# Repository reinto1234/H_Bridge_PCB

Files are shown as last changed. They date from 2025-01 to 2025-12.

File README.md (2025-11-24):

# H-Bridge PCB Project

## Project Description
This project involves the design and implementation of an **educational single-phase H-Bridge inverter** controlled by an **Espressif ESP32**.  
The system demonstrates **bipolar sinusoidal PWM (SPWM)** operation with **closed-loop VRMS amplitude control** and a **browser-based interface** for monitoring and control.  
The H-Bridge can drive loads with the following ratings:

- **Input Voltage:** 24 V  
- **Input Current:** up to 10 A  
- **Power:** ≈ 240 W  

### Features
- Fixed **switching frequency:** 35 kHz  
- Fixed **output frequency:** 50 Hz  
- **Bipolar SPWM modulation** (only)  
- **Closed-loop VRMS control** using PI regulation  
- **Web-based UI** (HTTP + WebSocket) for control and telemetry  
- **Input/Output power measurement**  
- **Overcurrent protection** using INA228 (auto driver shutdown + UI fault latch)  

The project consists of two main components:  
1. **H_Bridge_PCB_Design** — KiCad PCB layout and schematic.  
2. **H_Bridge_PCB_Code** — Firmware for the ESP32 controller.

---

## Directory Structure

<h2>Directory Structure</h2>
<pre><code>H_Bridge_PCB_Project/
├── H_Bridge_PCB_Design/        # KiCad design files
├── H_Bridge_PCB_Code/          # ESP32 firmware
│   ├── include/                # Header files
│   │   ├── Controller.h
│   │   ├── I2C.h
│   │   ├── Input_meas.h
│   │   ├── mutexdefinitions.h
│   │   ├── Output_meas.h
│   │   ├── PWM.h
│   │   ├── spi_sampler.h
│   │   ├── Tasks.h
│   │   └── webserver.h
│   │
│   ├── src/                    # Source files
│   │   ├── Controller.cpp
│   │   ├── I2C.cpp
│   │   ├── Input_meas.cpp
│   │   ├── Output_meas.cpp
│   │   ├── PWM.cpp
│   │   ├── spi_sampler.cpp
│   │   ├── Tasks.cpp
│   │   ├── webserver.cpp
│   │   └── main.cpp
│   │
│   ├── data/                   # Webserver files (LittleFS)
│   │   ├── index.html
│   │   ├── script.js
│   │   └── style.css
│
├── lib/                        # Optional local libraries
├── platformio.ini              # PlatformIO configuration
├── images/                     # Flowchart and figures
└── README.md                   # This file
</code></pre>

---

## Requirements

### Hardware:
- PCB based on KiCad design  
- 24 V DC power supply (≥ 10 A)  
- Resistive or inductive load (max ≈ 240 W)  
- Gate drivers with integrated dead-time  
- INA228 current/voltage monitor for input sensing  

### Software:
- [KiCad](https://www.kicad.org/) — PCB design  
- [PlatformIO](https://platformio.org/) — firmware build  
- [VS Code](https://code.visualstudio.com/) — recommended IDE  

---

## Webserver
The ESP32 provides a **built-in Wi-Fi access point** and hosts a **web-based interface** for control and measurement visualization.

### Connect to WLAN Access Point
- **SSID:** `H_Bridge_Control`  
- **Password:** `12345678`

### Open the web interface:
👉 [http://192.168.4.1/](http://192.168.4.1/)

**Functions:**
- Start/Stop the inverter  
- Set VRMS target  
- Display live telemetry (Vin, Iin, VRMS, IRMS, PF, P, Q, f)  
- View and acknowledge overcurrent faults  

---

## Code
The firmware is implemented in **C++** (Arduino / FreeRTOS).  
The web interface is built with **HTML**, **JavaScript**, and **CSS**.

---

### Flowchart
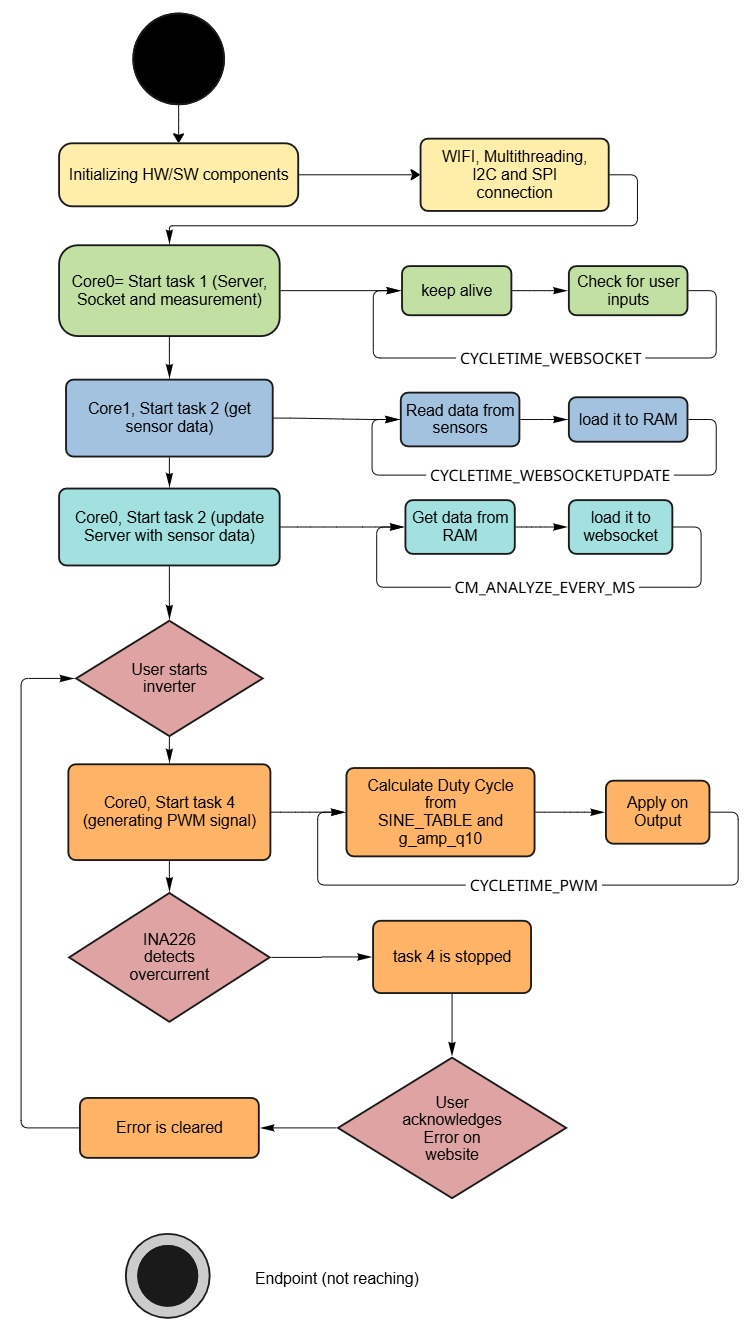
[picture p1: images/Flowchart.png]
Flowchart of the program


---

## Code Documentation
Brief overview of the most relevant components.

### Inverter Implementation (`PWM.cpp`)
Implements the real-time control of the full-bridge inverter:

- **startInverter()** — Initializes and enables PWM output.  
- **stopInverter()** — Stops PWM and resets inverter state.  
- **generateSPWM()** — Produces bipolar SPWM using a sine table.  
- **begin()** — Configures LEDC channels, frequency, and timers.  
- **getMeasurements()** — Retrieves latest measurement snapshot.  
- **computePI()** — Executes PI algorithm to maintain VRMS target.  
- **loop()** — Runs the inverter control logic at fixed timing intervals.  

### Controller Implementation (`Controller.cpp`)
Implements the PI controller used to regulate the inverter’s RMS output voltage:

- **PIController()** — Initializes PI gains, integrator state, limits, and VRMS target.  
- **ControlRMS()** — Computes RMS error and updates the global Q10 amplitude factor atomically.  
- **compute()** — Executes PI algorithm with anti-windup and output clamping to min/max limits.  
- **g_amp_q10** — Global Q10-formatted amplitude value used by the SPWM stage.  

### I²C Bus Setup (`I2C.cpp`)
Implements the I²C interface for the INA228 current/voltage sensor:

- **I2CINA** — Dedicated I²C bus instance (port 0) used by the input measurement subsystem.  

### Input Measurement (`Input_meas.cpp`)
Implements DC input voltage, current, and power measurement using INA228:

- **init()** — Initializes I²C bus, scans for devices, configures INA228, and sets averaging/timing.  
- **init1()** — Lightweight I²C initialization helper without full sensor setup.  
- **configure_overcurrent_alert_only()** — Configures INA228 alert registers for shunt overcurrent shutdown.  
- **getVoltage()** — Reads and returns the DC input voltage in volts.  
- **getCurrent()** — Reads and returns the shunt current in amperes.  
- **getPower()** — Reads and returns the input power in watts with simple error rejection.  
- **measurementall()** — Updates the shared input measurement buffer (voltage, current, power) in a mutex-protected way and returns it.  
- **scanI2C()** — Scans the I²C bus, prints found devices, and restarts the bus if no device is detected.  

### Main Application (`main.cpp`)
Implements system bring-up and FreeRTOS task orchestration:

- **setup()** — Initializes serial logging, mutexes, input measurement, Wi-Fi AP, webserver, SPI measurement engines, safety pins, and the overcurrent interrupt; then creates all application tasks.  
- **loop()** — Empty main loop; periodically yields since all logic is implemented in FreeRTOS tasks.  
- **Task handles** — Stores references to sampler, analyzer, WebSocket, controller, printer, and emergency stop tasks for debugging/management.  

### Mutex Definitions (`mutexdefinitions.cpp`)
Implements globally shared FreeRTOS mutexes for synchronization:

- **inverterMutex** — Protects access to the inverter state and control functions.  
- **measurementinMutex** — Protects shared input measurement buffer.  
- **measurementoutMutex** — Protects shared output measurement structures.  
- **measurementSpiMutex** — Protects SPI-related measurement buffers and state.  

### Output Measurement (`Output_meas.cpp`)
Implements decimation, CIC filtering, RMS, and frequency analysis for AMC1306 bitstreams:

- **buildByteCicLut()** — Precomputes CIC integrator/differentiator contributions for all 8-bit patterns.  
- **OutputMeasurements()** — Configures OSR, full-scale voltage, buffer sizes, and initial bit rate.  
- **init()** — Allocates decimation ring buffers, analysis windows, and period buffers (with PSRAM support) and creates a snapshot mutex.  
- **copyRecentWindowWithStats()** — Copies the newest segment from the decimation ring and computes mean, min, and max.  
- **findLastTwoRisingZcHyst()** — Detects the last two rising zero-crossings with hysteresis to define one AC period.  
- **computeRmsOnePeriodExact()** — Computes exact RMS over one period using piecewise linear interpolation.  
- **processRxBytesAndUpdateBitrate()** — Processes raw SPI bytes, runs CIC pipeline, generates decimated voltage samples, and updates effective bit rate.  
- **analyzeStep()** — Centers the signal, finds period boundaries, computes frequency, extracts a centered period, and calculates RMS.  
- **getSnapshot()** — Returns the latest snapshot (RMS, frequency, period length) in a thread-safe way.  
- **copyLastPeriod()** — Copies the last detected waveform period into a caller-provided buffer.  
- **copySinceSeq32()** — Provides incremental decimated samples since a given sequence index, for streaming or plotting.  

### Emergency Stop (`safety.cpp`)
Implements minimal emergency-stop signaling for overcurrent events:

- **g_emergency_stop** — Global volatile flag indicating an active emergency stop condition.  
- **onAlertISR()** — ISR that sets the emergency stop flag when the INA228 alert pin fires.  

### SPI Sampler (`spi_sampler.cpp`)
Implements DMA-driven SPI acquisition for dual AMC1306 isolated ADC channels:

- **g_ch1_om / g_ch2_om** — OutputMeasurements instances for both channels with hardware-specific scaling.  
- **g_sampler1 / g_sampler2** — Sampler context structures for SPI hosts, pins, DMA channels, and transactions.  
- **g_pack1 / g_pack2** — Pairs of sampler context and OutputMeasurements used by sampler tasks.  
- **spiSamplerInitMeasurements()** — Initializes both OutputMeasurements engines and validates buffer allocation.  
- **spiInitAndStart()** — Allocates DMA buffers, configures SPI bus and device, prepares transactions, and seeds the transaction queue.  

### Task Scheduler (`Tasks.cpp`)
Implements all FreeRTOS tasks for sampling, analysis, UI updates, control, and safety:

- **spiSamplerTask()** — Retrieves completed SPI DMA transactions, feeds data into OutputMeasurements, requeues transactions, and maintains sampling timing.  
- **analyzerTask()** — Periodically calls analyzeStep() on a given OutputMeasurements instance to update RMS and frequency.  
- **printerTask()** — Periodically prints analyzer timing, latest period samples, RMS, and frequency for both channels over serial.  
- **webSocketTask()** — Processes WebSocket events in a loop to keep client connections responsive.  
- **webSocketUpdate()** — Periodically collects input and output measurements and sends them as JSON via WebSocket to the UI.  
- **ControllerTask()** — Runs the VRMS control loop by feeding the measured RMS value into the PI controller of the inverter.  
- **EmergencyStopTask()** — Monitors the global emergency-stop flag, stops the inverter, signals the E-STOP output, and notifies the web UI when overcurrent is detected.  

### Webserver (`webserver.cpp`)
Implements Wi-Fi access point, HTTP endpoints, and WebSocket telemetry/UI control:

- **resetDefaults()** — Resets VRMS target and running state to their default values.  
- **initWiFi()** — Starts the Wi-Fi SoftAP for the H-Bridge control interface.  
- **initServer()** — Mounts LittleFS, serves static `/index.html`, `/style.css`, `/script.js`, and defines `/start`, `/stop`, and `/ack-trip` endpoints.  
- **updateMeasurements()** — Packs input/output data and frequency into JSON and broadcasts it over WebSocket.  
- **broadcastStatus()** — Sends current inverter running state to all connected clients via WebSocket.  
- **onWebSocketEvent()** — Handles client connect/disconnect events and sends initial status on connect.  
- **broadcastTrip()** — Notifies all clients of a trip condition and updates running state.  
- **_VRMS / _isRunning** — Static internal state for desired RMS value and inverter run/stop status.  

**HTTP Endpoints:**
- `/` – Main HTML page  
- `/start` – Start inverter  
- `/stop` – Stop inverter  
- `/update` – Update VRMS target  
- `/bipolar.png` – Waveform reference  

---

## Overcurrent Protection
Overcurrent protection is implemented through the **INA228** fault pin:  
1. When a current threshold is exceeded, **drivers are disabled immediately**.  
2. A **fault message** is sent to the web interface.  
3. After user acknowledgment, the inverter can be restarted safely.  

---

## Safety  
- Use **current-limited** power supplies during development.  
- Verify **MOSFET temperature and load** ratings.  
- For **educational/laboratory use only**.

---

## License
Released for **educational and research purposes**.  
Use responsibly.

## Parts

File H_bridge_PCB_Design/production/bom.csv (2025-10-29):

Designator | Footprint | Quantity | Value | LCSC Part #
C1, C6 | 0805 | 2 | 2.2 uF | C513763
C10, C13, C18, C19, C22, C24, C30, C33, C35, C9 | 0805 | 10 | 100 nF | C49678
C11, C17, C21, C25, C26, C27 | 0805 | 6 | 1µF | C28323
C12, C31, C32, C34, C36 | 0805 | 5 | 1 µF | C28323
C14, C15 | 0805 | 2 | 220nF | C354366
C16 | B32776E4406J000 | 1 | B32776E4406J000
C2, C4 | 0805 | 2 | 220 nF | C354366
C20 | 0805 | 1 | 4.7 µF | C49678
C23, C7, C8 | EEE1AA101SP | 3 | 100uF | C128464
C28, C29 | 0805 | 2 | 1 uF | C28323
C3, C5 | 0805 | 2 | 22 nF | C2181592
D1, D2, D3, D5 | FSV2060L | 4 | FSV2060L | C110669
D10, D11, D6, D7, D8, D9 | DIOM5336X265N | 6 | S210 | C184977
D12 | HPZRC26X | 1 | HPZR-C26X
D4 | SOT-143 | 1 | SP0503BAHT | C7074
FL1 | PHBC24N2R0A0219V | 1 | PHBC24N-2R0A0219V
IC1, IC3 | SOIC127P1150X280-8N | 2 | AMC1306M25DWVR | C471874
IC2 | L7812ABD2TTR | 1 | L7812ABD2T-TR | C186698
J1, J12, J14, J15, J2, J3, J4, J5, J7, J9 | TSW-102-XX-YY-S | 10 | TSW-102-15-T-S
J13 | 17345101 | 1 | 1734510-1 | C720612
LED1, LED4 | 0805 | 2 | TLMG1100-GS15-1 | C434436
LED2 | 0805 | 1 | TLMG1100-GS15-2 | C434436
LED3 | 0805 | 1 | TLMG1100-GS15-3 | C434436
PS1 | NXJ1S0303MCR13 | 1 | NXJ1S0303MC-R13 | C6943307
Q1, Q2, Q3, Q4 | TO254P483X1016X1994-3P | 4 | IRLB4030PBF | C2663
Q10, Q5, Q6, Q9 | IPD90N10S4L06ATMA1 | 4 | IPD90N10S4L06ATMA1
Q7, Q8 | SOT-23_Handsoldering | 2 | BC817 | C475629
R1, R10 | 0805 | 2 | 2.2 | C25301
R11, R27 | 0805 | 2 | 100 | C115423
R12 | 0805 | 1 | 1 | C4129769
R13, R18 | 0805 | 2 | 12k | C139925
R14 | 0805 | 1 | 5k | C2828700
R15, R42 | 2512 | 2 | GMR100HTBFER015 | C2985715
R16 | 0805 | 1 | 120k | C473315
R17, R28 | 0805 | 2 | 1k | C95781
R19, R20, R23, R24 | 0805 | 4 | 0 | C2074219
R2, R3, R8, R9 | 0805 | 4 | 10 | C3016584
R29 | 0805 | 1 | 330 | C4129769
R30, R31, R4, R40, R41, R5, R6, R7 | 0805 | 8 | 10k | C84376
S1 | B3U-1000P | 1 | B3U-1000P | C231329
TP1, TP2, TP3, TP4 | 5754 | 4 | 575-4
U1 | ESP32-WROOM-32 | 1 | ESP32-WROOM-32 | C701343
U2, U3 | SOIC-16W_7.5x10.3mm_P1.27mm | 2 | IR2110S | C2968
U4 | VSSOP-10_3x3mm_P0.5mm | 1 | INA228 | C2862904
U5 | SOT-223-3_TabPin2 | 1 | LT1963AxST-3.3 | C459918
U6 | TO-252-2 | 1 | LD1086DT50TR | C164853
U7 | SOIC-16_3.9x9.9mm_P1.27mm | 1 | CH340C | C84681

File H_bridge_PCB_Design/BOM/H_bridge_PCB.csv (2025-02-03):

Reference | Value | Footprint | Qty | DNP | LCSC Part#
C13,C16,C22 | MKS4C042204C00KSSD | SamacSys_Parts:MKS4C042204C00KSSD | 3
IC5 | ACS37800KMACTR-030B3-I2C | ACS37002LMCA050U5 | 1 | Nicht bestücken
J1,J2,J3,J4,J5,J6,J7,J8,J9,J10,J11 | TMS-102-21-G-S | SamacSys_Parts:TMS-102-YY-XX-S | 11 | Nicht bestücken
L1 | IH15BQ5R0K | SamacSys_Parts:IH15BQ5R0K | 1 | Nicht bestücken
Q1,Q2,Q3,Q4 | IRLB4030PBF | TO254P483X1016X1994-3P | 4 | Nicht bestücken
Q5,Q6,Q9,Q10 | IPD90N10S4L06ATMA1 | IPD90N10S4L06ATMA1 | 4 | Nicht bestücken
R46,R47 | 0 | Resistor_SMD:R_0805_2012Metric_Pad1.20x1.40mm_HandSolder | 2 | Nicht bestücken
TP1,TP2,TP3,TP4 | 575-4 | SamacSys_Parts:5754 | 4 | Nicht bestücken
U8 | 3544-2 | SamacSys_Parts:3544-2 | 1 | Nicht bestücken
P1 | USB_C_Plug_USB2.0 | Connector_USB:USB_C_Receptacle_HCTL_HC-TYPE-C-16P-01A | 1 |  | C2894897
U2,U3 | IR2110S | Package_SO:SOIC-16W_7.5x10.3mm_P1.27mm | 2 |  | C2968
D4 | SP0503BAHT | Package_TO_SOT_SMD:SOT-143 | 1 |  | C7074
U5 | LD1086DT33TR | Package_TO_SOT_SMD:TO-252-2 | 1 |  | C12051
U7 | CH340G | Package_SO:SOIC-16_3.9x9.9mm_P1.27mm | 1 |  | C14267
R1,R10 | 2.2 | Resistor_SMD:R_0805_2012Metric_Pad1.20x1.40mm_HandSolder | 2 |  | C25301
C11,C17,C21,C25,C26,C27 | 1µF | Resistor_SMD:R_0805_2012Metric_Pad1.20x1.40mm_HandSolder | 6 |  | C28323
C12 | 1 µF | Resistor_SMD:R_0805_2012Metric_Pad1.20x1.40mm_HandSolder | 1 |  | C28323
C10,C18,C19 | 100 nF | -- verschiedene Werte -- | 3 |  | C49678
R4,R5,R6,R7,R30,R31,R38,R39,R40,R41 | 10k | Resistor_SMD:R_0805_2012Metric_Pad1.20x1.40mm_HandSolder | 10 |  | C84376
R28 | 1k | Resistor_SMD:R_0805_2012Metric_Pad1.20x1.40mm_HandSolder | 1 |  | C95781
D1,D2,D3,D5 | FSV2060L | FSV2060L | 4 |  | C110669
R27 | 100 | Resistor_SMD:R_0805_2012Metric_Pad1.20x1.40mm_HandSolder | 1 |  | C115423
C7,C8,C23 | 100uF | SamacSys_Parts:EEE1AA101SP | 3 |  | C128464
R13 | 12k | Resistor_SMD:R_0805_2012Metric_Pad1.20x1.40mm_HandSolder | 1 |  | C139925
U6 | LD1086DT50TR | Package_TO_SOT_SMD:TO-252-2 | 1 |  | C164853
C9 | 1 nF | Resistor_SMD:R_0805_2012Metric_Pad1.20x1.40mm_HandSolder | 1 |  | C165822
D6,D7,D8,D9,D10,D11 | S210 | SamacSys_Parts:DIOM5336X265N | 6 |  | C184977
IC2 | L7812ABD2T-TR | L7812ABD2TTR | 1 |  | C186698
C2,C4 | 220 nF | Resistor_SMD:R_0805_2012Metric_Pad1.20x1.40mm_HandSolder | 2 |  | C354366
C14,C15 | 220nF | Resistor_SMD:R_0805_2012Metric_Pad1.20x1.40mm_HandSolder | 2 |  | C354366
LED1 | TLMG1100-GS15-1 | Resistor_SMD:R_0805_2012Metric_Pad1.20x1.40mm_HandSolder | 1 |  | C434436
LED2 | TLMG1100-GS15-2 | Resistor_SMD:R_0805_2012Metric_Pad1.20x1.40mm_HandSolder | 1 |  | C434436
LED3 | TLMG1100-GS15-3 | Resistor_SMD:R_0805_2012Metric_Pad1.20x1.40mm_HandSolder | 1 |  | C434436
Q7,Q8 | BC817 | Package_TO_SOT_SMD:SOT-23_Handsoldering | 2 |  | C475629
C1,C6 | 2.2 uF | Resistor_SMD:R_0805_2012Metric_Pad1.20x1.40mm_HandSolder | 2 |  | C513763
U1 | ESP32-WROOM-32 | RF_Module:ESP32-WROOM-32 | 1 |  | C701343
R23,R24,R48,R49 | 0 | Resistor_SMD:R_0805_2012Metric_Pad1.20x1.40mm_HandSolder | 4 |  | C2074219
C3,C5 | 22 nF | Resistor_SMD:R_0805_2012Metric_Pad1.20x1.40mm_HandSolder | 2 |  | C2181592
R15,R16,R43,R44 | 1M | Resistor_SMD:R_0805_2012Metric_Pad1.20x1.40mm_HandSolder | 4 |  | C2771009
R14 | 5k | Resistor_SMD:R_0805_2012Metric_Pad1.20x1.40mm_HandSolder | 1 |  | C2828700
U4 | INA228 | Package_SO:VSSOP-10_3x3mm_P0.5mm | 1 |  | C2862904
R42 | GMR100HTBFER015 | Resistor_SMD:R_2512_6332Metric_Pad1.40x3.35mm_HandSolder | 1 |  | C2985715
R2,R3,R8,R9 | 10 | Resistor_SMD:R_0805_2012Metric_Pad1.20x1.40mm_HandSolder | 4 |  | C3016584
R29 | 330 | Resistor_SMD:R_0805_2012Metric_Pad1.20x1.40mm_HandSolder | 1 |  | C4129769
R45 | 40k | Resistor_SMD:R_0805_2012Metric_Pad1.20x1.40mm_HandSolder | 1 |  | C5266069

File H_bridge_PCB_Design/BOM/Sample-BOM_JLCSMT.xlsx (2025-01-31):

Comment | Designator | Footprint | JLCPCB Part #（optional）
100uF | C1 | CAP-SMD_L3.5-W2.8 | C16133
15K | R5,R6 | R0603 | C22809
DC-005-20A_C136744 | DC1 | DC-IN-TH_DC-005-20A | C136744
Header-Female-2.54_1x8 | P2,P3 | HDR-TH_8P-P2.54-V | C27438
K2-1102DP-C4SW-04 | SW1 | KEY-TH_4P-L6.0-W6.0-P4.50-LS6.5 | C110153
ATMEGA328P-PU | U1 | DIP-28_L34.6-W7.3-P2.54-LS10.2-BL | C33901
670688000 | USB1 | USB-B-TH_67068-8000 | C114097

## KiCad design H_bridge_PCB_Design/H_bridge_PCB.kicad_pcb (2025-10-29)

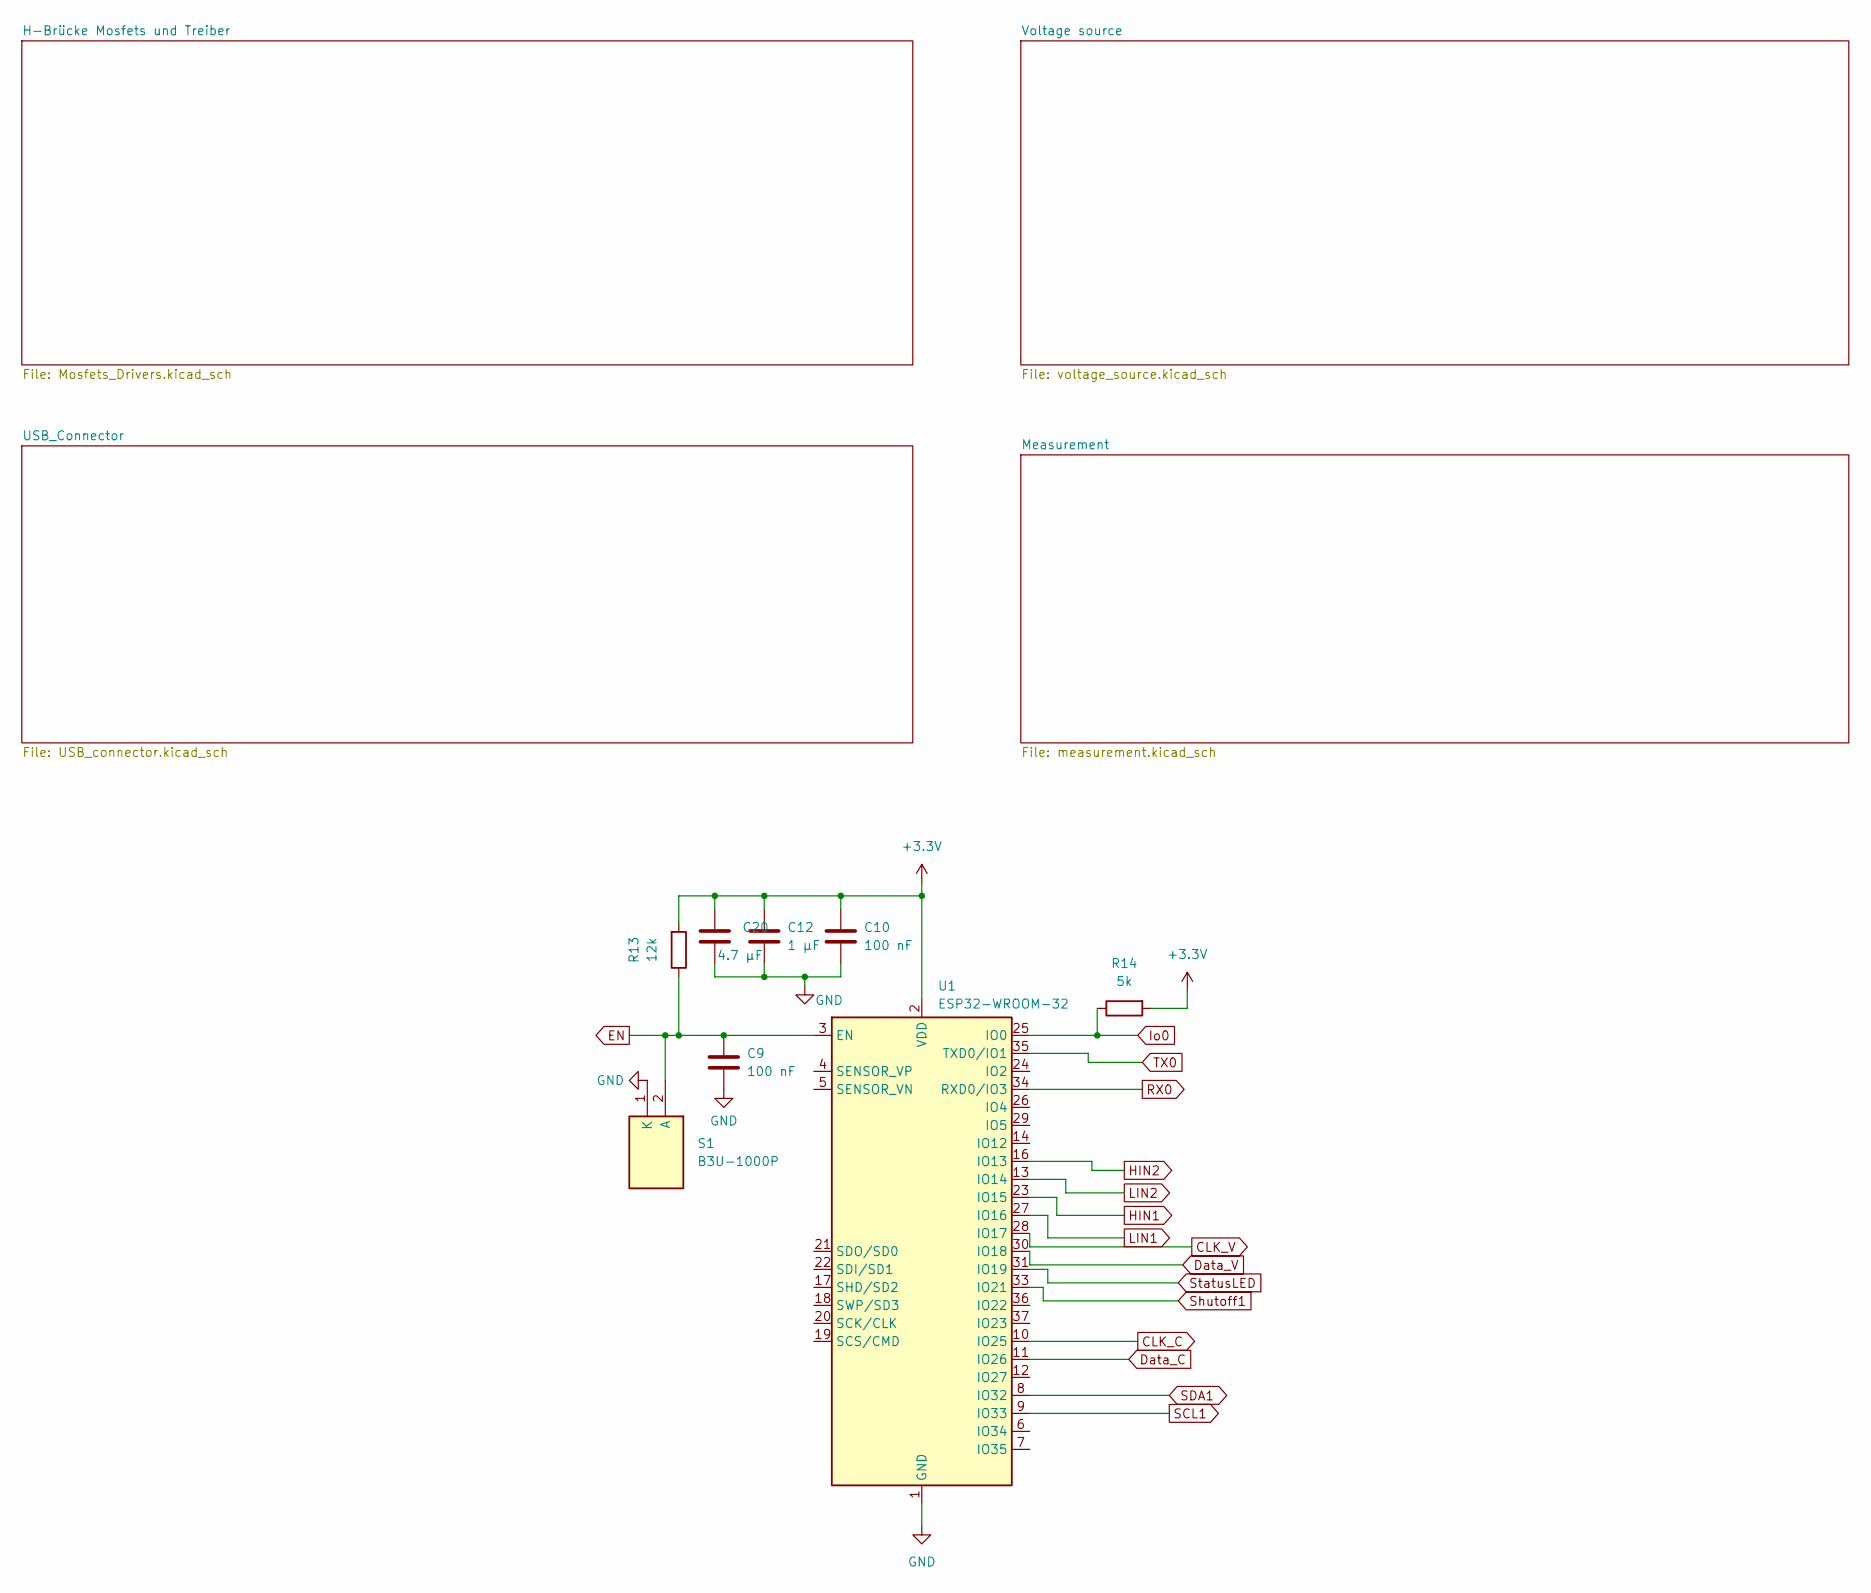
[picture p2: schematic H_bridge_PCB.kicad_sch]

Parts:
C9, C10: 100 nF; R_0805_2012Metric_Pad1.20x1.40mm_HandSolder; LCSC Part # C49678
C12: 1 µF; R_0805_2012Metric_Pad1.20x1.40mm_HandSolder; LCSC Part # C28323
C20: 4.7 µF; R_0805_2012Metric_Pad1.20x1.40mm_HandSolder; LCSC Part # C49678
R13: 12k; R_0805_2012Metric_Pad1.20x1.40mm_HandSolder; LCSC Part # C139925
R14: 5k; R_0805_2012Metric_Pad1.20x1.40mm_HandSolder; LCSC Part # C2828700
S1: B3U-1000P; Manufacturer_Part_Number B3U-1000P; Mouser Part Number 653-B3U-1000P
U1: ESP32-WROOM-32; LCSC Part # C701343

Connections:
+3.3V: C10.1, C12.1, C20.1, R13.2, R14.2, U1.2 (VDD); also elsewhere on the board
CLK_C: U1.10 (IO25); also elsewhere on the board
CLK_V: U1.28 (IO17); also elsewhere on the board
Data_C: U1.11 (IO26); also elsewhere on the board
Data_V: U1.30 (IO18); also elsewhere on the board
EN: C9.1, R13.1, S1.2 (A), U1.3 (EN); also elsewhere on the board
GND: C9.2, C10.2, C12.2, C20.2, S1.1 (K), U1.1 (GND), U1.15 (GND), U1.38 (GND), U1.39 (GND); also elsewhere on the board
HIN1: U1.23 (IO15); also elsewhere on the board
HIN2: U1.16 (IO13); also elsewhere on the board
Io0: R14.1, U1.25 (IO0); also elsewhere on the board
LIN1: U1.27 (IO16); also elsewhere on the board
LIN2: U1.13 (IO14); also elsewhere on the board
RX0: U1.34 (RXD0/IO3); also elsewhere on the board
SCL1: U1.9 (IO33); also elsewhere on the board
SDA1: U1.8 (IO32); also elsewhere on the board
Shutoff1: U1.33 (IO21); also elsewhere on the board
StatusLED: U1.31 (IO19)
TX0: U1.35 (TXD0/IO1); also elsewhere on the board

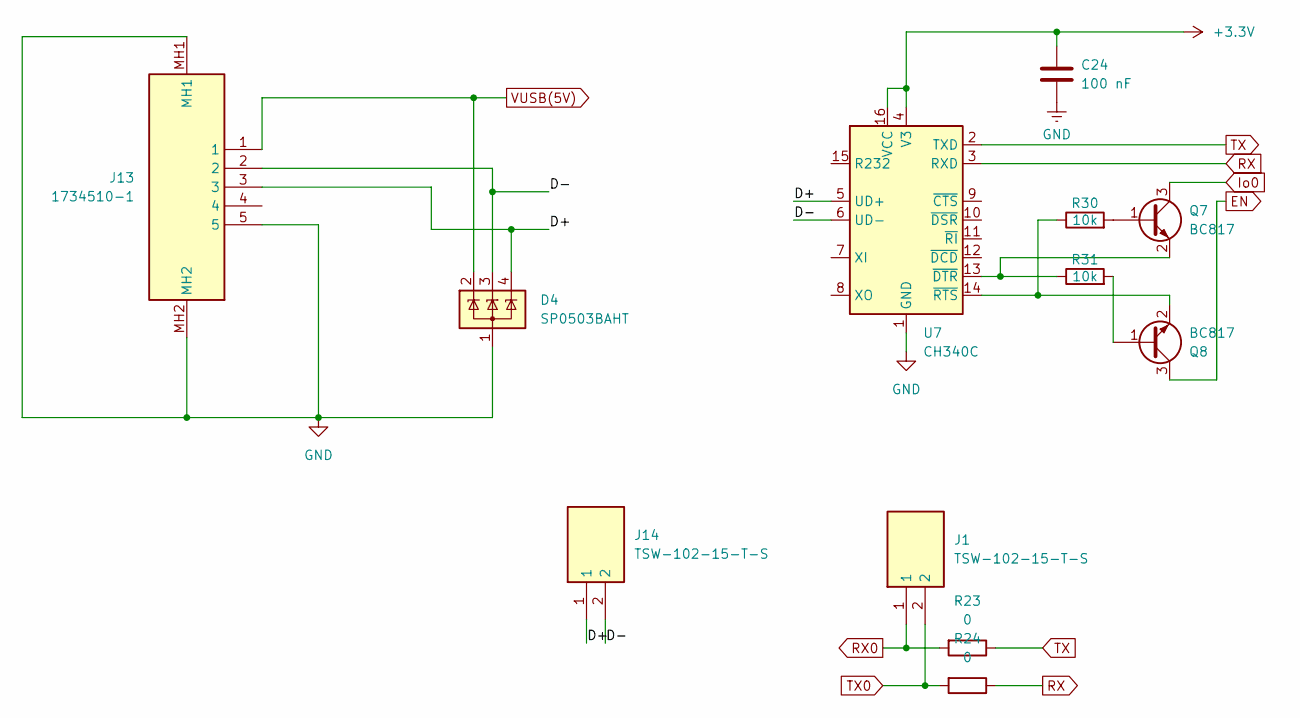
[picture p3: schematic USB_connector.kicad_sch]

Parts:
C24: 100 nF; R_0805_2012Metric_Pad1.20x1.40mm_HandSolder; LCSC Part # C49678
D4: SP0503BAHT; SOT-143; LCSC Part # C7074
J1, J14: TSW-102-15-T-S; TSW-102-XX-YY-S; Mouser Part Number 200-TSW10215TS
J13: 1734510-1; 17345101; Mouser Part Number 571-1734510-1
Q7, Q8: BC817; SOT-23_Handsoldering; LCSC Part # C475629
R23, R24: 0; R_0805_2012Metric_Pad1.20x1.40mm_HandSolder; LCSC Part # C2074219
R30, R31: 10k; R_0805_2012Metric_Pad1.20x1.40mm_HandSolder; LCSC Part # C84376
U7: CH340C; SOIC-16_3.9x9.9mm_P1.27mm; LCSC Part # C84681

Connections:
+3.3V: C24.1, U7.4 (V3), U7.16 (VCC); also elsewhere on the board
/USB_Connector/D+: D4.4 (K), J13.3, J14.1, U7.5 (UD+)
/USB_Connector/D-: D4.3 (K), J13.2, J14.2, U7.6 (UD-)
EN: Q8.3 (C); also elsewhere on the board
GND: C24.2, D4.1 (A), J13.5, J13.MH1, J13.MH2, U7.1 (GND); also elsewhere on the board
Io0: Q7.3 (C); also elsewhere on the board
unnamed: Q7.1 (B), R30.2
unnamed: Q7.2 (E), R31.1, U7.13 (~DTR)
unnamed: Q8.1 (B), R31.2
unnamed: Q8.2 (E), R30.1, U7.14 (~RTS)
RX: R24.1, U7.3 (RXD)
RX0: J1.1, R23.2; also elsewhere on the board
TX: R23.1, U7.2 (TXD)
TX0: J1.2, R24.2; also elsewhere on the board
VUSB(5V): D4.2 (K), J13.1; also elsewhere on the board

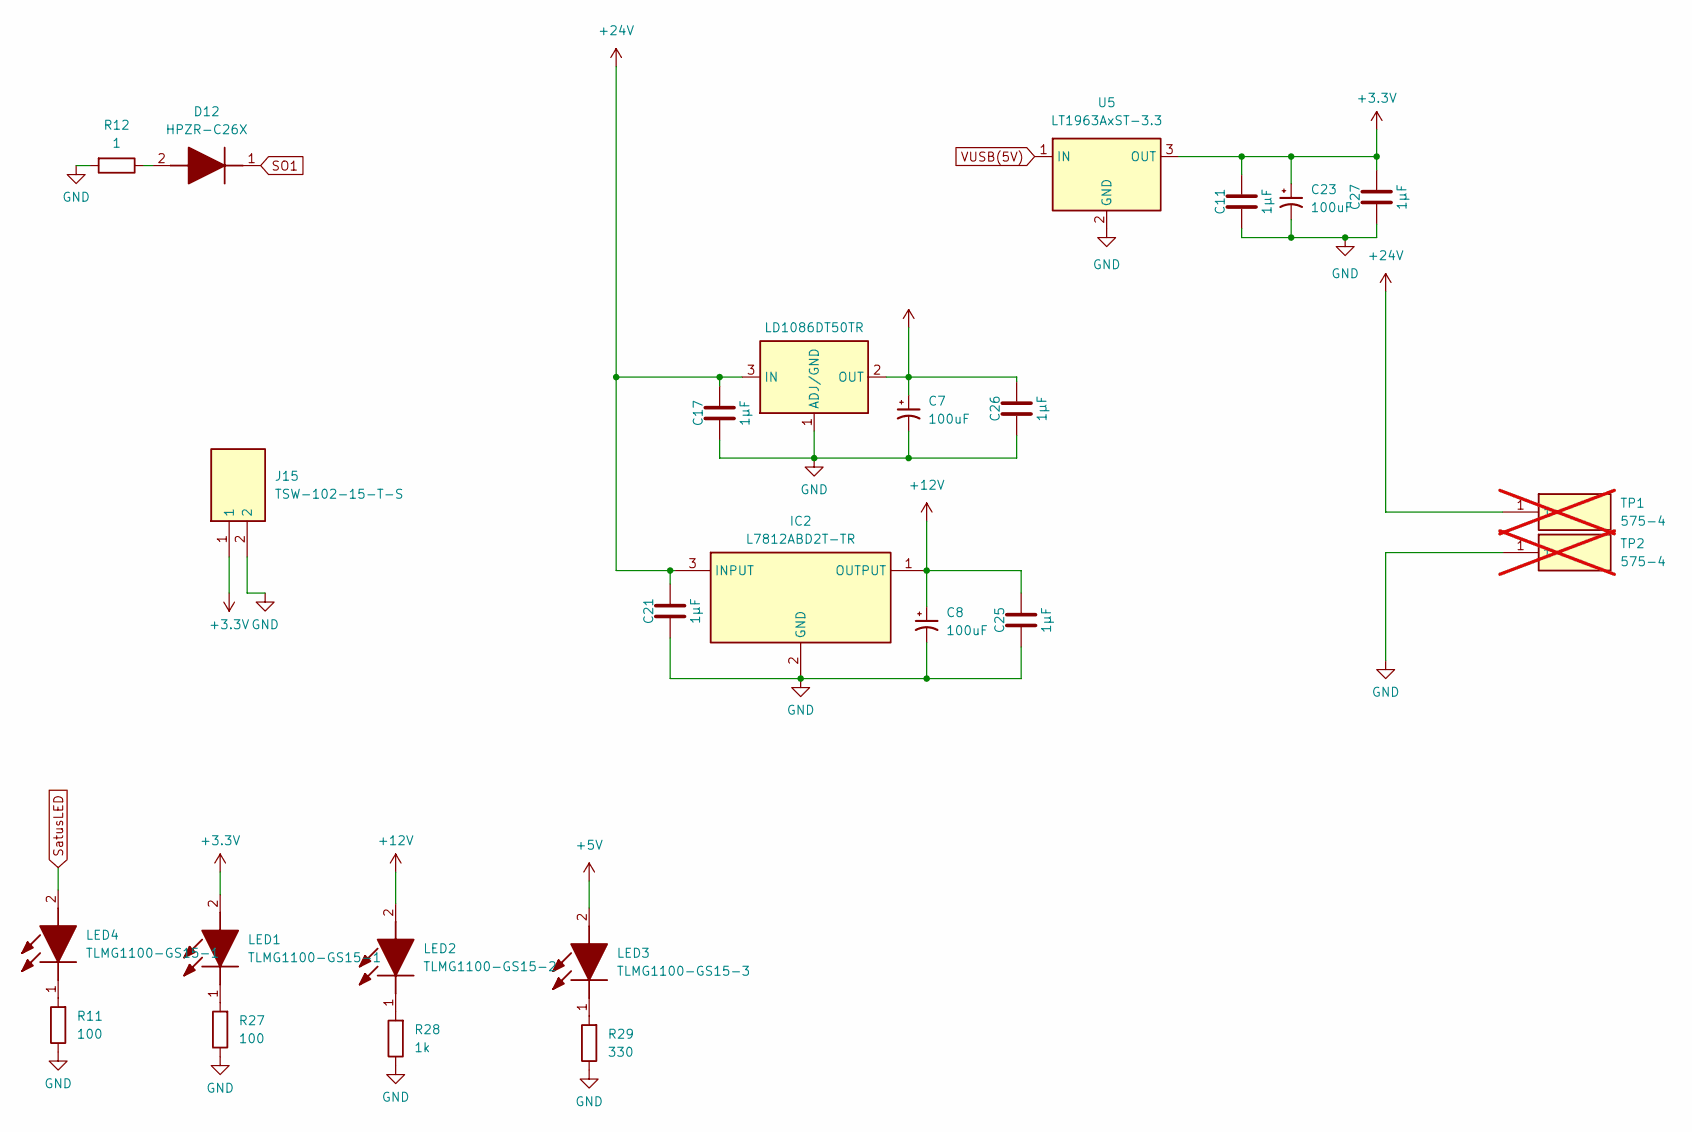
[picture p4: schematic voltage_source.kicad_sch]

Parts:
C7, C8, C23: 100uF; EEE1AA101SP; LCSC Part # C128464
C11, C17, C21, C25, C26, C27: 1µF; R_0805_2012Metric_Pad1.20x1.40mm_HandSolder; LCSC Part # C28323
D12: HPZR-C26X; HPZRC26X; Manufacturer_Part_Number HPZR-C26X
IC2: L7812ABD2T-TR; L7812ABD2TTR; Manufacturer_Part_Number L7812ABD2T-TR; Mouser Part Number 511-L7812ABD2T-TR
J15: TSW-102-15-T-S; TSW-102-XX-YY-S; Mouser Part Number 200-TSW10215TS
LED1, LED4: TLMG1100-GS15-1; R_0805_2012Metric_Pad1.20x1.40mm_HandSolder; Mouser Part Number 78-TLMG1100-GS15
LED2: TLMG1100-GS15-2; R_0805_2012Metric_Pad1.20x1.40mm_HandSolder; Mouser Part Number 78-TLMG1100-GS15
LED3: TLMG1100-GS15-3; R_0805_2012Metric_Pad1.20x1.40mm_HandSolder; Mouser Part Number 78-TLMG1100-GS15
R11, R27: 100; R_0805_2012Metric_Pad1.20x1.40mm_HandSolder; LCSC Part # C115423
R12: 1; R_0805_2012Metric_Pad1.20x1.40mm_HandSolder; LCSC Part # C4129769
R28: 1k; R_0805_2012Metric_Pad1.20x1.40mm_HandSolder; LCSC Part # C95781
R29: 330; R_0805_2012Metric_Pad1.20x1.40mm_HandSolder; LCSC Part # C4129769
TP1, TP2: 575-4; 5754; Mouser Part Number 534-575-4; not fitted
U5: LT1963AxST-3.3; SOT-223-3_TabPin2; LCSC Part # C459918
U6: LD1086DT50TR; TO-252-2; LCSC Part # C164853

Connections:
+3.3V: C11.1, C23.1, C27.1, J15.1, LED1.2 (A), U5.3 (OUT); also elsewhere on the board
+5V: C7.1, C26.1, LED3.2 (A), U6.2 (OUT); also elsewhere on the board
+12V: C8.1, C25.1, IC2.1 (OUTPUT), LED2.2 (A); also elsewhere on the board
GND: C7.2, C8.2, C11.2, C17.2, C21.2, C23.2, C25.2, C26.2, C27.2, IC2.2 (GND), J15.2, R11.1, R12.2, R27.1, R28.1, R29.1, TP2.1, U5.2 (GND), U6.1 (ADJ/GND); also elsewhere on the board
unnamed: D12.2 (A), R12.1
unnamed: LED1.1 (K), R27.2
unnamed: LED2.1 (K), R28.2
unnamed: LED3.1 (K), R29.2
unnamed: LED4.1 (K), R11.2
SO1: D12.1 (K); also elsewhere on the board
SatusLED: LED4.2 (A)
VUSB(5V): U5.1 (IN); also elsewhere on the board

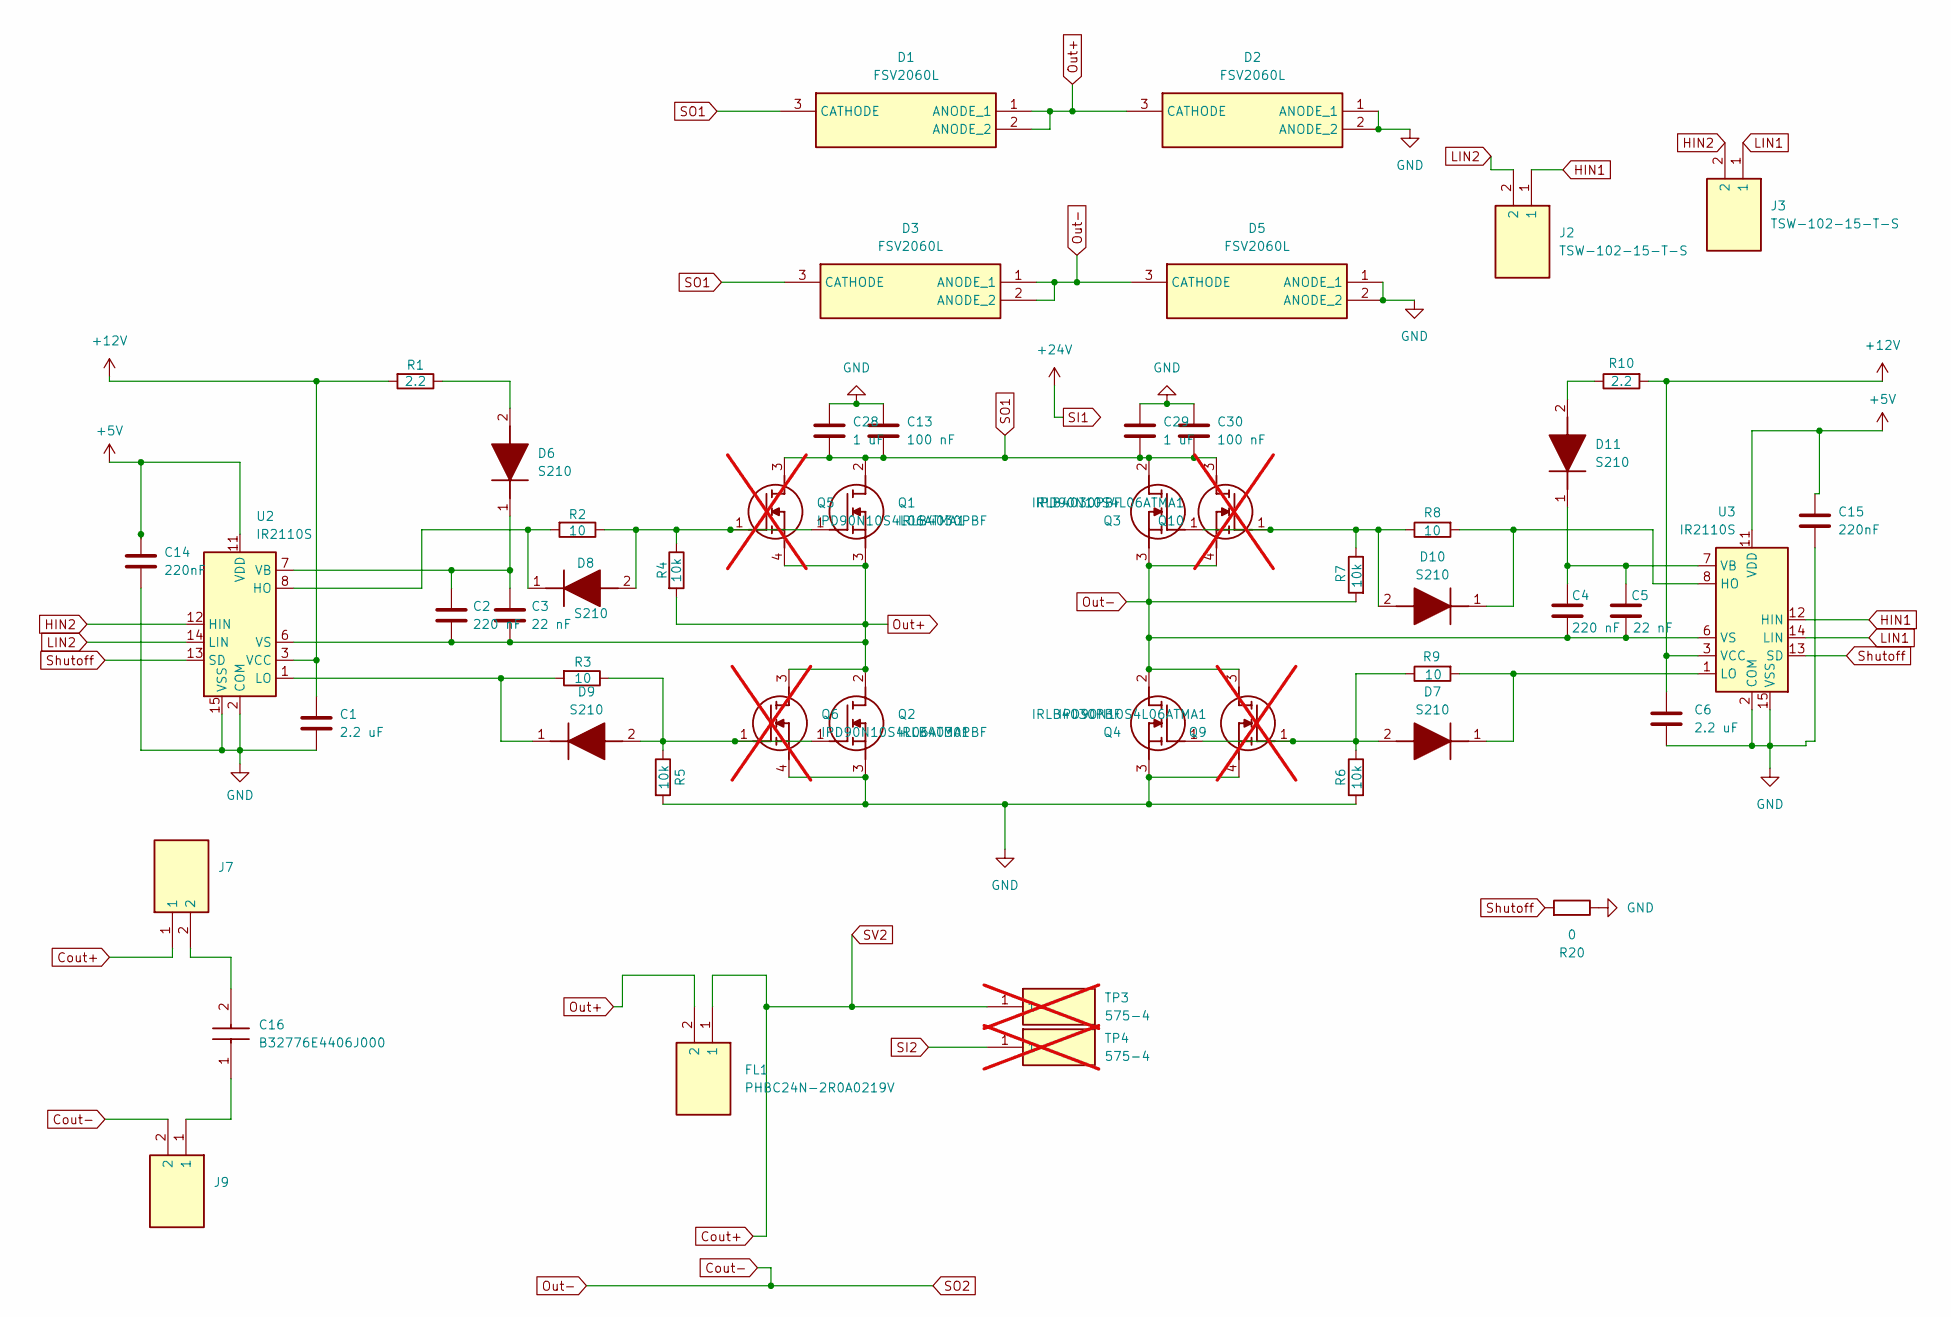
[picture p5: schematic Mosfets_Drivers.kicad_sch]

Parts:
C1, C6: 2.2 uF; R_0805_2012Metric_Pad1.20x1.40mm_HandSolder; LCSC Part # C513763
C2, C4: 220 nF; R_0805_2012Metric_Pad1.20x1.40mm_HandSolder; LCSC Part # C354366
C3, C5: 22 nF; R_0805_2012Metric_Pad1.20x1.40mm_HandSolder; LCSC Part # C2181592
C13, C30: 100 nF; R_0805_2012Metric_Pad1.20x1.40mm_HandSolder; LCSC Part # C49678
C14, C15: 220nF; R_0805_2012Metric_Pad1.20x1.40mm_HandSolder; LCSC Part # C354366
C16: B32776E4406J000; Mouser Part Number 871-B32776E4406J000
C28, C29: 1 uF; R_0805_2012Metric_Pad1.20x1.40mm_HandSolder; LCSC Part # C28323
D1, D2, D3, D5: FSV2060L; Mouser Part Number 512-FSV2060L
D6, D7, D8, D9, D10, D11: S210; DIOM5336X265N; Manufacturer_Part_Number S210; Mouser Part Number 512-S210
FL1: PHBC24N-2R0A0219V; PHBC24N2R0A0219V; Mouser Part Number 80-PHBC24N-2R0A0219V
J2, J3, J7, J9: TSW-102-15-T-S; TSW-102-XX-YY-S; Mouser Part Number 200-TSW10215TS
Q1, Q2, Q3, Q4: IRLB4030PBF; TO254P483X1016X1994-3P; Mouser Part Number 942-IRLB4030PBF
Q5, Q6, Q9, Q10: IPD90N10S4L06ATMA1; Mouser Part Number 726-IPD90N10S4L06ATM; not fitted
R1, R10: 2.2; R_0805_2012Metric_Pad1.20x1.40mm_HandSolder; LCSC Part # C25301
R2, R3, R8, R9: 10; R_0805_2012Metric_Pad1.20x1.40mm_HandSolder; LCSC Part # C3016584
R4, R5, R6, R7: 10k; R_0805_2012Metric_Pad1.20x1.40mm_HandSolder; LCSC Part # C84376
R20: 0; R_0805_2012Metric_Pad1.20x1.40mm_HandSolder; LCSC Part # C2074219
TP3, TP4: 575-4; 5754; Mouser Part Number 534-575-4; not fitted
U2, U3: IR2110S; SOIC-16W_7.5x10.3mm_P1.27mm; LCSC Part # C2968

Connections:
+5V: C14.1, C15.1, U2.11 (VDD), U3.11 (VDD); also elsewhere on the board
+12V: C1.1, C6.1, R1.2, R10.2, U2.3 (VCC), U3.3 (VCC); also elsewhere on the board
Cout+: FL1.1, J7.1, TP3.1; also elsewhere on the board
Cout-: C4.2, C5.2, D3.1 (ANODE_1), D3.2 (ANODE_2), D5.3 (CATHODE), J9.2, Q3.3 (S), Q4.2 (D), Q9.3 (D), Q10.4 (S), R7.2, U3.6 (VS); also elsewhere on the board
GND: C1.2, C6.2, C13.2, C14.2, C15.2, C28.2, C29.2, C30.2, D2.1 (ANODE_1), D2.2 (ANODE_2), D5.1 (ANODE_1), D5.2 (ANODE_2), Q2.3 (S), Q4.3 (S), Q6.4 (S), Q9.4 (S), R5.2, R6.2, R20.1, U2.2 (COM), U2.15 (VSS), U3.2 (COM), U3.15 (VSS); also elsewhere on the board
HIN1: J2.1, U3.12 (HIN); also elsewhere on the board
HIN2: J3.2, U2.12 (HIN); also elsewhere on the board
LIN1: J3.1, U3.14 (LIN); also elsewhere on the board
LIN2: J2.2, U2.14 (LIN); also elsewhere on the board
unnamed: C16.1, J9.1
unnamed: C16.2, J7.2
unnamed: D6.2 (A), R1.1
unnamed: C2.1, C3.1, D6.1 (K), U2.7 (VB)
unnamed: D7.2 (A), Q4.1 (G), Q9.1 (G), R6.1, R9.1
unnamed: D7.1 (K), R9.2, U3.1 (LO)
unnamed: D8.2 (A), Q1.1 (G), Q5.1 (G), R2.1, R4.1
unnamed: D8.1 (K), R2.2, U2.8 (HO)
unnamed: D9.2 (A), Q2.1 (G), Q6.1 (G), R3.1, R5.1
unnamed: D9.1 (K), R3.2, U2.1 (LO)
unnamed: D10.2 (A), Q3.1 (G), Q10.1 (G), R7.1, R8.1
unnamed: D10.1 (K), R8.2, U3.8 (HO)
unnamed: D11.2 (A), R10.1
unnamed: C4.1, C5.1, D11.1 (K), U3.7 (VB)
Out+: C2.2, C3.2, D1.1 (ANODE_1), D1.2 (ANODE_2), D2.3 (CATHODE), FL1.2, Q1.3 (S), Q2.2 (D), Q5.4 (S), Q6.3 (D), R4.2, U2.6 (VS)
SI2: TP4.1; also elsewhere on the board
SO1: C13.1, C28.1, C29.1, C30.1, D1.3 (CATHODE), D3.3 (CATHODE), Q1.2 (D), Q3.2 (D), Q5.3 (D), Q10.3 (D); also elsewhere on the board
Shutoff: R20.2, U2.13 (SD), U3.13 (SD); also elsewhere on the board

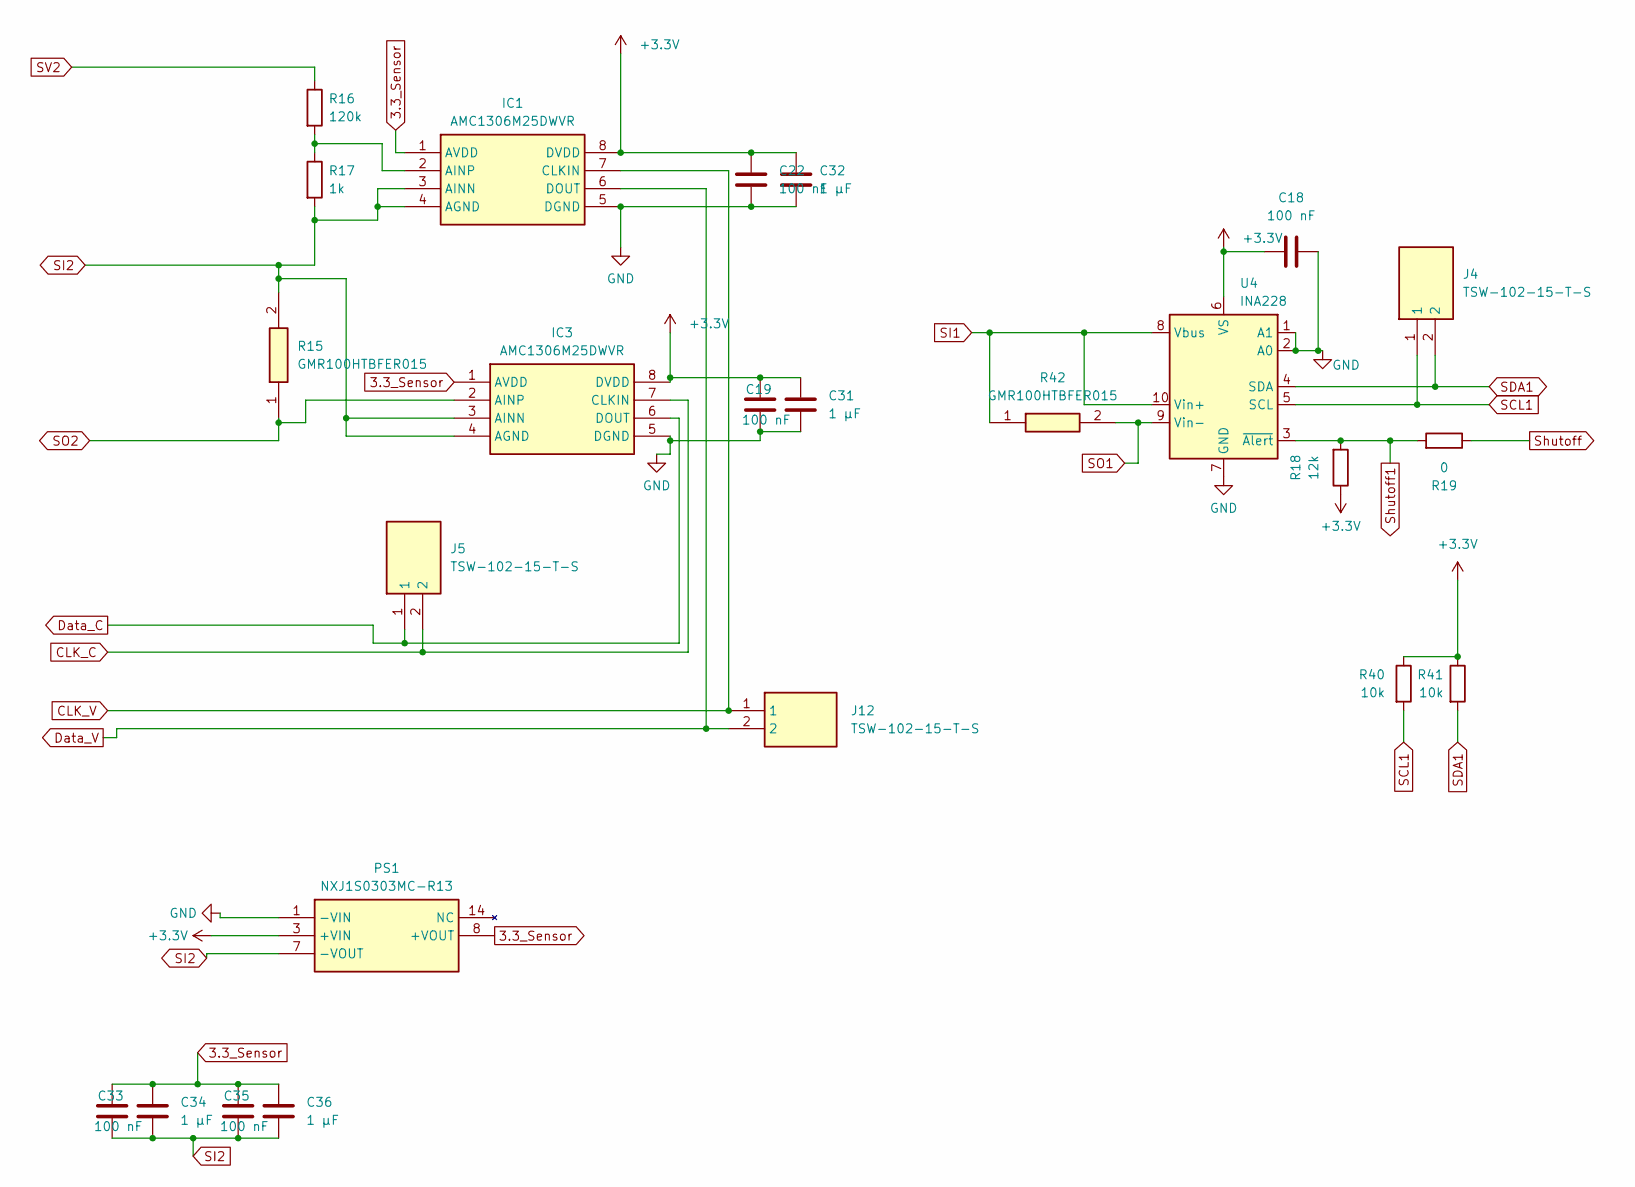
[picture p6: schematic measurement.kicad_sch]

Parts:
C18, C19, C22, C33, C35: 100 nF; R_0805_2012Metric_Pad1.20x1.40mm_HandSolder; LCSC Part # C49678
C31, C32, C34, C36: 1 µF; R_0805_2012Metric_Pad1.20x1.40mm_HandSolder; LCSC Part # C28323
IC1, IC3: AMC1306M25DWVR; SOIC127P1150X280-8N; Mouser Part Number 595-AMC1306M25DWVR
J4, J5, J12: TSW-102-15-T-S; TSW-102-XX-YY-S; Mouser Part Number 200-TSW10215TS
PS1: NXJ1S0303MC-R13; NXJ1S0303MCR13; Mouser Part Number 580-NXJ1S0303MC-R13
R15, R42: GMR100HTBFER015; R_2512_6332Metric_Pad1.40x3.35mm_HandSolder; Mouser Part Number 755-GMR100HTBFER015
R16: 120k; R_0805_2012Metric_Pad1.20x1.40mm_HandSolder; LCSC Part # C473315
R17: 1k; R_0805_2012Metric_Pad1.20x1.40mm_HandSolder; LCSC Part # C95781
R18: 12k; R_0805_2012Metric_Pad1.20x1.40mm_HandSolder; LCSC Part # C139925
R19: 0; R_0805_2012Metric_Pad1.20x1.40mm_HandSolder; LCSC Part # C2074219
R40, R41: 10k; R_0805_2012Metric_Pad1.20x1.40mm_HandSolder; LCSC Part # C84376
U4: INA228; VSSOP-10_3x3mm_P0.5mm; LCSC Part # C2862904

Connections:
3.3_Sensor: C33.2, C34.2, C35.2, C36.2, IC1.1 (AVDD), IC3.1 (AVDD), PS1.8 (+VOUT)
+3.3V: C18.1, C19.2, C22.2, C31.2, C32.2, IC1.8 (DVDD), IC3.8 (DVDD), PS1.3 (+VIN), R18.1, R40.1, R41.1, U4.6 (VS); also elsewhere on the board
CLK_C: IC3.7 (CLKIN), J5.2; also elsewhere on the board
CLK_V: IC1.7 (CLKIN), J12.1; also elsewhere on the board
Cout+: R16.1; also elsewhere on the board
Cout-: IC3.2 (AINP), R15.1; also elsewhere on the board
Data_C: IC3.6 (DOUT), J5.1; also elsewhere on the board
Data_V: IC1.6 (DOUT), J12.2; also elsewhere on the board
GND: C18.2, C19.1, C22.1, C31.1, C32.1, IC1.5 (DGND), IC3.5 (DGND), PS1.1 (-VIN), U4.1 (A1), U4.2 (A0), U4.7 (GND); also elsewhere on the board
unnamed: IC1.2 (AINP), R16.2, R17.1
SCL1: J4.1, R40.2, U4.5 (SCL); also elsewhere on the board
SDA1: J4.2, R41.2, U4.4 (SDA); also elsewhere on the board
SI2: C33.1, C34.1, C35.1, C36.1, IC1.3 (AINN), IC1.4 (AGND), IC3.3 (AINN), IC3.4 (AGND), PS1.7 (-VOUT), R15.2, R17.2; also elsewhere on the board
SO1: R42.2, U4.9 (Vin-); also elsewhere on the board
Shutoff: R19.1; also elsewhere on the board
Shutoff1: R18.2, R19.2, U4.3 (~Alert); also elsewhere on the board

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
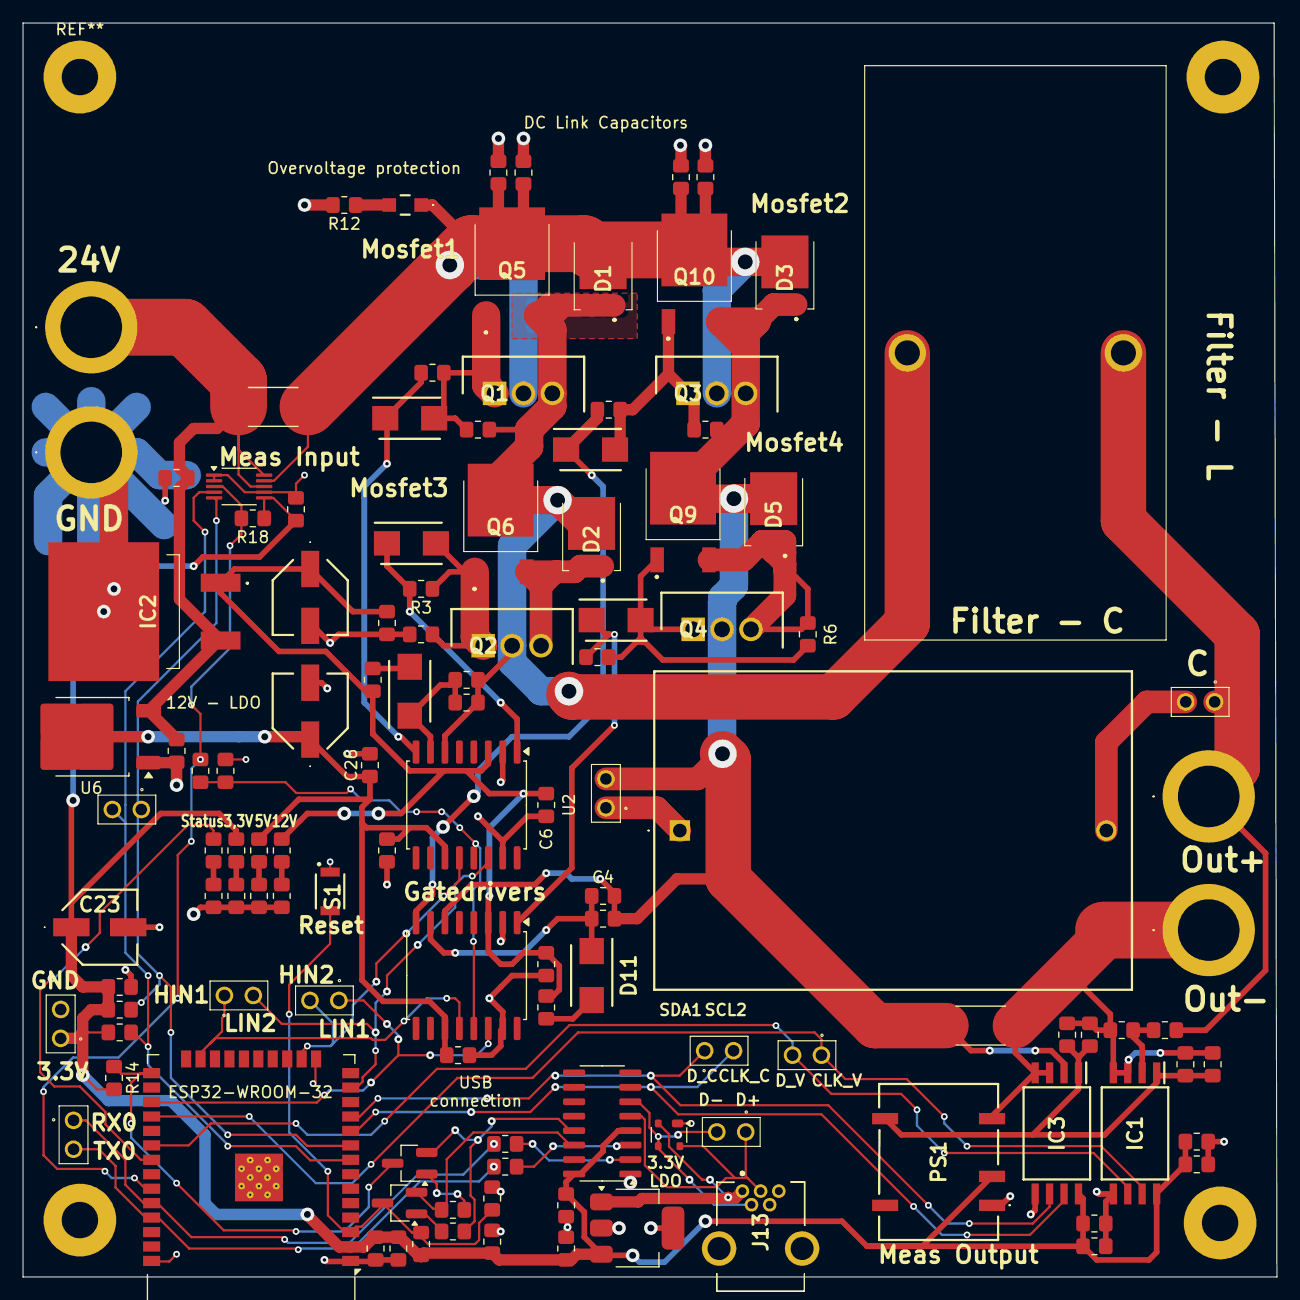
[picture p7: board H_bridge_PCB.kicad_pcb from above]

Board: 2 copper layers, 110.2 x 110.2 mm, 120 parts (0 on the bottom side), 56 nets.

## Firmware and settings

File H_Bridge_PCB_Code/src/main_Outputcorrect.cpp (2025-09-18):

// /************************************************************************
//  * @file main.cpp
//  * @brief Multithreaded main for H-Bridge Inverter + AMC1306 SPI-DMA capture
//  ************************************************************************/

// #include <Arduino.h>
// #include <math.h>
// #include <string.h>

// extern "C" {
//   #include "freertos/FreeRTOS.h"
//   #include "freertos/task.h"
//   #include "freertos/semphr.h"
//   #include "driver/spi_master.h"
//   #include "driver/gpio.h"
//   #include "esp_system.h"
//   #include "esp_heap_caps.h"
//   #include "esp_timer.h"
//   #include "esp_log.h"
// }

// // ---- Your app headers ----
// #include "PWM.h"
// #include "webserver.h"
// #include "mutexdefinitions.h"
// #include "Input_meas.h"

// #define OM_DECIM_RING_DEFAULT 4096
// #define OM_MAX_SCAN_DEFAULT   2048

// // ---- Output measurement engine (AMC1306 CIC/ZC/RMS) ----
// #include "Output_meas.h"   // provides OutputMeasurements + OM_* defines

// // ---------- App cadence (web layer) ----------
// #define CYCLETIME_WEBSOCKET_UPDATE 500   // ms
// #define CYCLETIME_WEBSOCKET        10    // ms

// // ---------- SPI / DMA & Pins for two AMC1306 channels ----------
// #define CH1_PIN_SCLK   17
// #define CH1_PIN_MISO   18
// #define CH1_PIN_MOSI   -1
// #define CH1_PIN_CS     -1

// #define CH2_PIN_SCLK   25   // AMC1306 #2 CLKIN -> ESP32 SCLK (VSPI)
// #define CH2_PIN_MISO   26   // AMC1306 #2 DOUT  -> ESP32 MISO (VSPI)
// #define CH2_PIN_MOSI   -1
// #define CH2_PIN_CS     -1

// #define CH1_SPI_HOST      VSPI_HOST
// #define CH1_DMA_CHAN      1
// #define CH2_SPI_HOST      HSPI_HOST
// #define CH2_DMA_CHAN      2

// #define F_CLK_HZ          5000000      // SPI clk per host
// #define SPI_MODE          1

// #define CHUNK_BYTES       2048         // per DMA transaction
// #define QUEUE_DEPTH       3            // triple-buffer
// #define NUM_DMA_BUFS      3


// // Optional console printer (diagnostic)
// #define PRINT_EVERY_MS    10000

// #ifndef SPICOMMON_BUSFLAG_MASTER
// #define SPICOMMON_BUSFLAG_MASTER 0
// #endif

// //static float g_dummyInput[3] = {0.0f, 0.0f, 0.0f};

// static const char* TAG = "HB-INV+AMC1306";

// // ===== Channel-scoped measurement engines (dual AMC1306) =====
// static OutputMeasurements ch1_om(/*osr*/ OM_OSR, /*fs_mv*/ OM_FS_MV*121.0f, /*init bitrate*/ (float)F_CLK_HZ);
// static OutputMeasurements ch2_om(/*osr*/ OM_OSR, /*fs_mv*/ OM_FS_MV*10.0f, /*init bitrate*/ (float)F_CLK_HZ);

// // ===== Sampler (per SPI host) =====
// typedef struct {
//   spi_device_handle_t dev;
//   spi_transaction_t   trans[NUM_DMA_BUFS];
//   uint8_t*            rxbuf[NUM_DMA_BUFS];
//   uint8_t*            txdummy;
//   int pin_sclk, pin_miso, pin_mosi, pin_cs;
//   spi_host_device_t host;
//   int dma_chan;
// } sampler_ctx_t;

// static sampler_ctx_t g_sampler1 = { .pin_sclk=CH1_PIN_SCLK, .pin_miso=CH1_PIN_MISO,
//   .pin_mosi=CH1_PIN_MOSI, .pin_cs=CH1_PIN_CS, .host=CH1_SPI_HOST, .dma_chan=CH1_DMA_CHAN };

// static sampler_ctx_t g_sampler2 = { .pin_sclk=CH2_PIN_SCLK, .pin_miso=CH2_PIN_MISO,
//   .pin_mosi=CH2_PIN_MOSI, .pin_cs=CH2_PIN_CS, .host=CH2_SPI_HOST, .dma_chan=CH2_DMA_CHAN };

// // ---------- Task Handles ----------
// TaskHandle_t webSocketUpdateHandle = NULL;
// TaskHandle_t webSocketTaskHandle   = NULL;
// TaskHandle_t spiSampler1Handle     = NULL;
// TaskHandle_t spiSampler2Handle     = NULL;
// TaskHandle_t analyzer1Handle       = NULL;
// TaskHandle_t analyzer2Handle       = NULL;
// TaskHandle_t printerHandle         = NULL;

// // ===== SPI init/start (per sampler) =====
// static void spi_init_and_start(sampler_ctx_t* s) {
//   // DMA buffers
//   for (int i = 0; i < NUM_DMA_BUFS; ++i) {
//     s->rxbuf[i] = (uint8_t*)heap_caps_malloc(CHUNK_BYTES, MALLOC_CAP_DMA | MALLOC_CAP_8BIT);
//     if (!s->rxbuf[i]) { ESP_LOGE(TAG, "RX DMA alloc fail"); abort(); }
//   }
//   s->txdummy = (uint8_t*)heap_caps_malloc(CHUNK_BYTES, MALLOC_CAP_DMA | MALLOC_CAP_8BIT);
//   if (!s->txdummy) { ESP_LOGE(TAG, "TX dummy alloc fail"); abort(); }
//   memset(s->txdummy, 0xFF, CHUNK_BYTES);

//   // SPI bus
//   spi_bus_config_t buscfg = {};
//   buscfg.mosi_io_num     = s->pin_mosi;
//   buscfg.miso_io_num     = s->pin_miso;
//   buscfg.sclk_io_num     = s->pin_sclk;
//   buscfg.quadwp_io_num   = -1;
//   buscfg.quadhd_io_num   = -1;
//   buscfg.max_transfer_sz = CHUNK_BYTES;
//   buscfg.flags           = SPICOMMON_BUSFLAG_MASTER;
//   buscfg.intr_flags      = 0;
//   ESP_ERROR_CHECK(spi_bus_initialize(s->host, &buscfg, s->dma_chan));

//   // Device
//   spi_device_interface_config_t devcfg = {};
//   devcfg.mode             = SPI_MODE;
//   devcfg.clock_speed_hz   = F_CLK_HZ;
//   devcfg.spics_io_num     = s->pin_cs;
// #ifdef SPI_DEVICE_NO_DUMMY
//   devcfg.flags            = SPI_DEVICE_NO_DUMMY;
// #else
//   devcfg.flags            = 0;
// #endif
//   devcfg.queue_size       = QUEUE_DEPTH;
//   ESP_ERROR_CHECK(spi_bus_add_device(s->host, &devcfg, &s->dev));

//   // Transactions
//   for (int i = 0; i < NUM_DMA_BUFS; ++i) {
//     spi_transaction_t* t = &s->trans[i];
//     memset(t, 0, sizeof(*t));
//     t->length    = CHUNK_BYTES * 8;
//     t->rxlength  = 0;
//     t->tx_buffer = s->txdummy;
//     t->rx_buffer = s->rxbuf[i];
//   }

//   for (int i = 0; i < NUM_DMA_BUFS; ++i)
//     ESP_ERROR_CHECK(spi_device_queue_trans(s->dev, &s->trans[i], portMAX_DELAY));
// }

// // ===== Sampler tasks (one per SPI host) =====
// static void spi_sampler_task(void* arg) {
//   auto* pack = (std::pair<sampler_ctx_t*, OutputMeasurements*>*)arg;
//   sampler_ctx_t* s = pack->first;
//   OutputMeasurements* OM = pack->second;

//   uint64_t last_us = esp_timer_get_time();
//   while (true) {
//     spi_transaction_t* rtrans = nullptr;
//     esp_err_t e = spi_device_get_trans_result(s->dev, &rtrans, portMAX_DELAY);
//     if (e != ESP_OK) { ESP_LOGE(TAG, "get_trans_result err=%d", e); continue; }

//     uint64_t now_us = esp_timer_get_time();
//     uint64_t dt_us  = now_us - last_us;
//     last_us = now_us;

//     OM->processRxBytesAndUpdateBitrate((const uint8_t*)rtrans->rx_buffer, CHUNK_BYTES, dt_us);
//     ESP_ERROR_CHECK(spi_device_queue_trans(s->dev, rtrans, portMAX_DELAY));
//     taskYIELD();
//   }
// }

// // ===== Analyzer task (per channel) =====
// static void analyzer_task(void* arg) {
//   OutputMeasurements* OM = (OutputMeasurements*)arg;
//   uint32_t last_ms = 0;
//   while (true) {
//     uint32_t now = millis();
//     if ((uint32_t)(now - last_ms) >= OM_ANALYZE_EVERY_MS) { // from Output_meas.h
//       last_ms = now;
//       OM->analyzeStep();
//     }
//     vTaskDelay(1);
//   }
// }

// // ===== Optional: console printer task (diagnostic) =====
// static void printer_task(void* arg) {
//   (void)arg;
//   uint32_t last_ms = 0;

//   static float tmp_period1[OM_MAX_PERIOD_BUF];
//   static float tmp_period2[OM_MAX_PERIOD_BUF];

//   while (true) {
//     uint32_t now = millis();
//     if ((uint32_t)(now - last_ms) >= PRINT_EVERY_MS) {
//       last_ms = now;

//       OutputMeasurements::Snapshot s1{}, s2{};
//       bool ok1 = ch1_om.getSnapshot(s1);
//       bool ok2 = ch2_om.getSnapshot(s2);
//       const int dt1 = ch1_om.analyzeEndUs() - ch1_om.analyzeStartUs();
//       const int dt2 = ch2_om.analyzeEndUs() - ch2_om.analyzeStartUs();

//       // CH1
//       Serial.println("ch1_analyzer_dt_us=" + String(dt1));
//       Serial.print("ch1_period_csv=");
//       if (!ok1 || s1.n_period == 0) {
//         Serial.println();
//       } else {
//         uint16_t n = ch1_om.copyLastPeriod(tmp_period1, OM_MAX_PERIOD_BUF);
//         for (uint16_t i = 0; i < n; ++i) {
//           Serial.print(tmp_period1[i], 3); Serial.print(',');
//           if ((i & 0x1FF) == 0x1FF) vTaskDelay(1);
//         }
//         Serial.println();
//       }
//       Serial.print("ch1_freq_hz="); if (ok1 && isfinite(s1.freq_hz)) Serial.println(s1.freq_hz, 2); else Serial.println("nan");
//       Serial.print("ch1_rms_mV=");  if (ok1 && s1.n_period)         Serial.println(s1.rms_mV, 3);   else Serial.println("nan");

//       // CH2
//       Serial.println("ch2_analyzer_dt_us=" + String(dt2));
//       Serial.print("ch2_period_csv=");
//       if (!ok2 || s2.n_period == 0) {
//         Serial.println();
//       } else {
//         uint16_t n = ch2_om.copyLastPeriod(tmp_period2, OM_MAX_PERIOD_BUF);
//         for (uint16_t i = 0; i < n; ++i) {
//           Serial.print(tmp_period2[i], 3); Serial.print(',');
//           if ((i & 0x1FF) == 0x1FF) vTaskDelay(1);
//         }
//         Serial.println();
//       }
//       Serial.print("ch2_freq_hz="); if (ok2 && isfinite(s2.freq_hz)) Serial.println(s2.freq_hz, 2); else Serial.println("nan");
//       Serial.print("ch2_rms_mV=");  if (ok2 && s2.n_period)         Serial.println(s2.rms_mV, 3);   else Serial.println("nan");
//     }
//     vTaskDelay(pdMS_TO_TICKS(100));
//   }
// }

// // ===== WebSocket loop task =====
// static void webSocketTask(void *pvParameters) {
//   (void)pvParameters;
//   while (true) {
//     HBridgeWebServer::loopWebSocket();
//     vTaskDelay(pdMS_TO_TICKS(CYCLETIME_WEBSOCKET));
//   }
// }

// // ===== Periodic WebSocket update task =====
// // Pulls Input measurements and AMC1306 OutputMeasurements (freq/RMS) and sends to clients.
// static void webSocketUpdate(void *pvParameters) {
//   (void)pvParameters;

//   // You can change the size/layout if your UI expects different fields.
//   static float outBuf[7]; // [0]=ch1_freq, [1]=ch1_rms_mV, [2]=ch2_freq, [3]=ch2_rms_mV, rest reserved

//   while (true) {
//     float* inBuf = InputMeasurement::measurementall(); // your existing function
//     //float* inBuf = g_dummyInput; // dummy if InputMeasurement is not used

//     // Build output array from AMC1306 analyzers
//     OutputMeasurements::Snapshot s1{}, s2{};
//     ch1_om.getSnapshot(s1);
//     ch2_om.getSnapshot(s2);

//     outBuf[0] = (s1.n_period > 0)    ? s1.rms_mV  : NAN;
//     outBuf[1] = (s2.n_period > 0)    ? s2.rms_mV  : NAN;
//     outBuf[2] = 0.0f;
//     outBuf[3] = 0.0f;
//     outBuf[4] = 0.0f;
//     outBuf[5] = 0.0f;
//     outBuf[6] = isfinite(s1.freq_hz) ? s1.freq_hz : NAN;

//     HBridgeWebServer::updateMeasurements(inBuf, outBuf);

//     vTaskDelay(pdMS_TO_TICKS(CYCLETIME_WEBSOCKET_UPDATE));
//   }
// }

// // ===== Arduino entry =====
// void setup() {
//   Serial.begin(115200);
//   delay(100);
//   ESP_LOGI(TAG, "Start H-Bridge + AMC1306 dual capture (DMA triple-buffer + analyzer + Web)");

//   // --- Your app init ---
//   inverterMutex      = xSemaphoreCreateMutex();
//   measurementinMutex = xSemaphoreCreateMutex();
//   measurementoutMutex= xSemaphoreCreateMutex();

//   InputMeasurement::init();



//   // --- WiFi / WebServer ---
//   HBridgeWebServer::initWiFi();
//   HBridgeWebServer::initServer();
//   Serial.println("WebServer initialized!");

//     // --- Init AMC1306 measurement engines ---
//   if (!ch1_om.init("CH1") || !ch2_om.init("CH2")) {
//     Serial.println("FATAL: OutputMeasurements init failed");
//     abort();
//   }

//   // --- Start SPI engines ---
//   spi_init_and_start(&g_sampler1);
//   spi_init_and_start(&g_sampler2);

//   // Pack for sampler tasks
//   static std::pair<sampler_ctx_t*, OutputMeasurements*> pack1 = { &g_sampler1, &ch1_om };
//   static std::pair<sampler_ctx_t*, OutputMeasurements*> pack2 = { &g_sampler2, &ch2_om };

//   Serial.println("Starting tasks...");

//   // --- Create tasks ---
//   // Samplers: high priority, separate core assignments are fine
//   xTaskCreatePinnedToCore(spi_sampler_task, "spi_sampler_ch1",
//                           4096, &pack1, configMAX_PRIORITIES - 2, &spiSampler1Handle, 1);
//   xTaskCreatePinnedToCore(spi_sampler_task, "spi_sampler_ch2",
//                           4096, &pack2, configMAX_PRIORITIES - 2, &spiSampler2Handle, 1);

//   // Analyzers: medium priority
//   xTaskCreatePinnedToCore(analyzer_task, "analyzer_ch1",
//                           6144, &ch1_om, 2, &analyzer1Handle, 1);
//   xTaskCreatePinnedToCore(analyzer_task, "analyzer_ch2",
//                           6144, &ch2_om, 3, &analyzer2Handle, 1);

//    //WebSocket loop + periodic updates (core 0 to keep WiFi stack happy)
//   xTaskCreatePinnedToCore(webSocketTask, "WebSocketTask",
//                           4096, NULL, 1, &webSocketTaskHandle, 0);
//   xTaskCreatePinnedToCore(webSocketUpdate, "WebSocketUpdate",
//                           4096, NULL, 1, &webSocketUpdateHandle, 0);

//   // Optional console printer (low prio)
//   xTaskCreatePinnedToCore(printer_task, "printer",
//                           4096, NULL, 2, &printerHandle, 0);

//                           Serial.printf("heap free=%u  (8bit=%u  dma=%u  internal=%u)\n",
//   esp_get_free_heap_size(),
//   heap_caps_get_free_size(MALLOC_CAP_8BIT),
//   heap_caps_get_free_size(MALLOC_CAP_DMA),
//   heap_caps_get_free_size(MALLOC_CAP_INTERNAL));
// }

// void loop() {
//   // nothing — everything runs in tasks
//   vTaskDelay(pdMS_TO_TICKS(1000));
// }

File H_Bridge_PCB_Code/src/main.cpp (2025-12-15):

// *************************************************************************
//  @file main.cpp
//  @brief Minimal main: just initialization + task creation + loop
// *************************************************************************

#include <Arduino.h>

extern "C" {
  #include "freertos/FreeRTOS.h"
  #include "freertos/task.h"
  #include "freertos/semphr.h"
  #include "esp_log.h"
}
      // new: sampler/analyzer/web tasks + contexts
#include "mutexdefinitions.h" // your existing mutex externs/defs
#include "Input_meas.h"
#include "webserver.h"
#include "spi_sampler.h"
#include "Tasks.h"
#include "safety.h"

static const char* TAG = "HB-INV+AMC1306";

TaskHandle_t webSocketUpdateHandle = NULL;
TaskHandle_t webSocketTaskHandle   = NULL;
TaskHandle_t spiSampler1Handle     = NULL;
TaskHandle_t spiSampler2Handle     = NULL;
TaskHandle_t analyzer1Handle       = NULL;
TaskHandle_t analyzer2Handle       = NULL;
TaskHandle_t printerHandle         = NULL;
TaskHandle_t ControllerTaskHandle  = NULL;
TaskHandle_t estopTaskHandle       = NULL;

void setup() {
  Serial.begin(115200);
  delay(100);
  ESP_LOGI(TAG, "Start H-Bridge + AMC1306 dual capture (DMA triple-buffer + analyzer + Web)");

  // --- Your app init ---
  inverterMutex       = xSemaphoreCreateMutex();
  measurementinMutex  = xSemaphoreCreateMutex();
  measurementoutMutex = xSemaphoreCreateMutex();

  InputMeasurement::init();

  // --- WiFi / WebServer ---
  HBridgeWebServer::initWiFi();
  HBridgeWebServer::initServer();
  Serial.println("WebServer initialized!");

  // --- Init AMC1306 measurement engines ---
  if (!spiSamplerInitMeasurements()) {
    Serial.println("FATAL: OutputMeasurements init failed");
    abort();
  }

  // --- Start SPI engines (both) ---
  spiInitAndStart(&g_sampler1);
  spiInitAndStart(&g_sampler2);

  pinMode(ALERT_PIN, INPUT);  // external 3k3 pull-up present, don't use INPUT_PULLUP
  attachInterrupt(digitalPinToInterrupt(ALERT_PIN), onAlertISR, RISING);
  pinMode(ESTOP_OUTPUT_PIN, OUTPUT);
  digitalWrite(ESTOP_OUTPUT_PIN, HIGH); // active HIGH
  delay(500);
  digitalWrite(ESTOP_OUTPUT_PIN, LOW);  // deactivate estop output after delay
  delay(500);
  digitalWrite(ESTOP_OUTPUT_PIN, HIGH); // active HIGH
  delay(500);
  digitalWrite(ESTOP_OUTPUT_PIN, LOW);  // deactivate estop output after delay


  Serial.println("Starting tasks...");

  // --- Create tasks ---
  // Samplers: high priority
  xTaskCreatePinnedToCore(spiSamplerTask, "spi_sampler_ch1",
                          4096, &g_pack1, configMAX_PRIORITIES - 2, &spiSampler1Handle, 1);
  xTaskCreatePinnedToCore(spiSamplerTask, "spi_sampler_ch2",
                          4096, &g_pack2, configMAX_PRIORITIES - 2, &spiSampler2Handle, 1);

  // Analyzers: medium priority
  xTaskCreatePinnedToCore(analyzerTask, "analyzer_ch1",
                          6144, &g_ch1_om, 2, &analyzer1Handle, 1);
  xTaskCreatePinnedToCore(analyzerTask, "analyzer_ch2",
                          6144, &g_ch2_om, 2, &analyzer2Handle, 1);

  // WebSocket loop + periodic updates (core 0 to keep WiFi stack happy)
  xTaskCreatePinnedToCore(webSocketTask, "WebSocketTask",
                          4096, NULL, 3, &webSocketTaskHandle, 0);
  xTaskCreatePinnedToCore(webSocketUpdate, "WebSocketUpdate",
                          4096, NULL, 2, &webSocketUpdateHandle, 0);

  //xTaskCreatePinnedToCore(printerTask, "printer",
  //                                4096, NULL, 1, &printerHandle, 0);

  xTaskCreatePinnedToCore(ControllerTask, "ControllerTask",
                          4096, NULL, 4, &ControllerTaskHandle, 0);

  xTaskCreatePinnedToCore(EmergencyStopTask, "EmergencyStop",
                            2048, nullptr, configMAX_PRIORITIES-1,
                            &estopTaskHandle, 0);

  
Serial.printf("heap free=%u  (8bit=%u  dma=%u  internal=%u)\n",
  esp_get_free_heap_size(),
  heap_caps_get_free_size(MALLOC_CAP_8BIT),
  heap_caps_get_free_size(MALLOC_CAP_DMA),
  heap_caps_get_free_size(MALLOC_CAP_INTERNAL));
}

void loop() {
  // nothing — everything runs in tasks
  vTaskDelay(pdMS_TO_TICKS(1000));
}

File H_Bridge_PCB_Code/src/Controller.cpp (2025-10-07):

/************************************************************************
 * @file Controller.cpp
 * @brief Controller implementation for the controller module
 *
 * This file contains the implementation of the controller, including
 * the PI controller logic.
 ************************************************************************/
#include "Controller.h"
#include <math.h>
#include "mutexdefinitions.h" // Mutex-Definitionen einbinden

// Define the static variable with DRAM_ATTR at file scope
DRAM_ATTR int16_t PIController::g_amp_q10 = 307;   //initial value 0,3 maximum 1023: 1,0
// Place this at the top of the file, after includes, if not already present:
// DRAM_ATTR uint32_t Controller::g_amp_q10 = 1023;

// Constructor
PIController::PIController(float kp, float ki, float outputMin, float outputMax, float vrms)
    : kp(kp), ki(ki), outputMin(outputMin), outputMax(outputMax), integral(0.0f), prevError(0.0f), vrms(vrms) {
    // Initialization of g_amp_q10 should be done at declaration, not here
}

// Control RMS voltage
void PIController::ControlRMS(float* RMSvoltage) {
    // Mutex für Thread-Sicherheit verwenden
    if (RMSvoltage != nullptr && !std::isnan(*RMSvoltage)) {
        float factortemp = compute(vrms, *RMSvoltage); // Example usage
        //Serial.println(*RMSvoltage);
        //Serial.println(factortemp);
        int16_t temp = factortemp * 1023; // Store the computed factor in Q10 format
        __atomic_store_n(&g_amp_q10, temp, __ATOMIC_RELEASE); // Atomically update g_amp_q10
    }
    else{
        __atomic_store_n(&g_amp_q10, 1023*outputMin, __ATOMIC_RELEASE); // Reset to default factor
    }
   //g_amp_q10 = 1023*outputMax; // Always set to max for now
}

// Compute PI controller output
float PIController::compute(float setpoint, float measurement) {
    float error = setpoint - measurement;
    float inttemp = integral;
    integral += ki*error;

    float output = (kp * error) + (integral);
    //Serial.print("PI output: ");
    //Serial.println(output);
    if (output > outputMax) {
        output = outputMax;
        if (integral > inttemp) integral = inttemp; // Anti-windup
    }
    if (output < outputMin) {
        output = outputMin;
        if (integral < inttemp) integral = inttemp; // Anti-windup
    }
    //Serial.print("Adjusted PI output: ");
    //Serial.println(output);

    return output;
}

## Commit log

2025-02-03 Updated PCB design files
    [H_bridge_PCB-B_Cu.gbr, H_bridge_PCB-B_Mask.gbr, H_bridge_PCB-B_Paste.gbr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]
2025-02-04 added PWM generation and connected to webserver
2025-02-06 Updated website no apply button and output frquency added
2025-02-17 Added picutres for bipolar and unipolar, changed pins for I2C-2
    [H_bridge_PCB.kicad_pcb, H_bridge_PCB.kicad_sch]
2025-03-14 updated pwm VERY IMPORTANT
    [H_bridge_PCB-B_Cu.gbr, H_bridge_PCB-B_Mask.gbr, H_bridge_PCB-B_Paste.gbr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]
2025-05-22 Interrupt for PWM and unipolar modulation
    [H_bridge_PCB-B_Cu.gbr, H_bridge_PCB-B_Mask.gbr, H_bridge_PCB-B_Paste.gbr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]
2025-06-27 -Changed PCB Layout now with 2x 3.3V also from usb, and to different ground planes -Measurement output now correctly parametrized -Stop sequence changed for SC protection
    [PWM.cpp, PWM.h, main.cpp]
2025-09-02 huge changes output measurement
    [H_bridge_PCB-B_Cu.gbr, H_bridge_PCB-B_Mask.gbr, H_bridge_PCB-B_Paste.gbr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]
2025-09-18 measurement of current and voltage correct no controlling. main smaller. no comments yet
    [main.cpp, main_Outputcorrect.cpp, spi_sampler.cpp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]
2025-10-29 new pcb
    [H_bridge_PCB-B_Cu.gbr, H_bridge_PCB-B_Mask.gbr, H_bridge_PCB-B_Paste.gbr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]
2025-11-13 Overcurrent protection
    [measurement.kicad_sch]
